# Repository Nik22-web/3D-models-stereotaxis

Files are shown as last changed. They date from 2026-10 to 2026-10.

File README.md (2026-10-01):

# 3D-models-stereotaxis

Рисунок1

# A 3D-Printed Open-Source Stereotaxic Platform for Orthotopic Glioma Cell Implantation into the Mouse Striatum

This repository contains the design files and assembly documentation associated with the manuscript:

**A 3D-Printed Open-Source Stereotaxic Platform for Orthotopic Glioma Cell Implantation into the Mouse Striatum**

**Authors:**  
Kurtova A.I., Esetov N.S., Khamitova Ya.D., Nosov M., Shipunova V.O.

---

## Overview

This repository provides the 3D-printable design files and assembly information required to reproduce and adapt the custom-built stereotaxic platform described in the associated manuscript.

The system consists of:

- one caliper-based needle manipulator;
- two mouse fixation frames;
- 3D-printed structural components;
- commercially available mechanical hardware.

The platform was developed for orthotopic implantation of glioma cells into the mouse striatum and was designed as a low-cost, modular alternative to conventional stereotaxic equipment.

---

## Repository version

The version of this repository corresponding to the manuscript and Supplementary Table S1 is tagged as:

`v1.0-manuscript`

This version should be used when reproducing the configuration described in the manuscript.

---

## Repository contents

The repository contains STL files for the following components developed for the present stereotaxic system:

### Mouse fixation frame support legs

- `first base platform leg.stl`
- `second base platform leg.stl`

### Caliper holder assembly

- `caliper holder.stl`
- `first depth gauge lock.stl`
- `second depth gauge lock.stl`

### Needle retainer

- `needle retainer base.stl`
- `clamping insert.stl`

### Tooth bar assembly

- `bite plate.stl`
- `manual adjustment knob.stl`
- `nose holder.stl`

Additional components of the mouse fixation frame are derived from an upstream open-source stereotaxic/anesthesia platform, as described below.

---

# Assembly Instructions

## 1. Needle retainer assembly

The needle retainer provides rigid fixation of the injection needle while allowing rapid insertion and replacement.

### Components

- needle retainer base;
- clamping insert;
- M3 screw;
- M3 hex nut;
- injection needle.

### Assembly

1. Insert the **M3 hex nut** into the recessed pocket of the clamping insert.
2. Position the **clamping insert** inside the lower slot of the needle retainer base.
3. Mount the assembled needle retainer onto the microscope holder.
4. Insert the **M3 screw** and thread it into the M3 hex nut.
5. Leave sufficient clearance for insertion of the injection needle.
6. Insert the needle and tighten the M3 screw until the needle is securely fixed.

Avoid excessive tightening to prevent damage to the printed components.

---

## 2. Mouse tooth bar assembly

The tooth bar assembly consists of:

- bite plate;
- nose holder;
- manual adjustment knob;
- M6 locking bolt;
- M6 receiving nut;
- retraction spring.

The bite plate contains a central aperture for positioning the upper incisors, while the nose holder prevents upward movement of the anterior part of the head.

### Assembly

1. Insert the **M6 receiving nut** into the recessed pocket of the bite plate.
2. Position the **retraction spring** inside the lower portion of the nose holder.
3. Insert the **nose holder** into the bite plate.
4. Mount the **manual adjustment knob** onto the M6 locking bolt.
5. Insert the locking bolt through the upper opening of the bite plate.
6. Thread the bolt into the M6 receiving nut.
7. Rotate the manual adjustment knob to adjust the position of the nose holder and the clamping force.

---

## 3. Mechanical caliper installation

The mechanical vernier caliper is used to determine vertical needle displacement.

### Installation

1. Attach the **caliper holder** to the upper rail of the microscope stand.
2. Insert the upper jaw of the mechanical caliper into the holder.
3. Verify that the caliper depth gauge moves freely through the corresponding slot in the microscope stand rail.
4. Adjust the caliper position if necessary.
5. Remove the original screw securing the movable microscope stage.
6. Install the **depth gauge retainer** in its place.
7. Insert the caliper depth gauge into the retainer.
8. Secure the depth gauge using the clamping plate.
9. Fasten the assembly using the original microscope-stage screw.
10. After correct alignment has been confirmed, secure the caliper mounting components with adhesive to prevent displacement during stereotaxic procedures.

---

## 4. Needle and catheter installation

Before use:

1. Insert a 29- or 30-gauge needle into polyethylene or PTFE catheter tubing with an inner diameter of approximately 0.3 mm.
2. Place the catheter–needle assembly vertically into the needle retainer.
3. Secure the needle using the locking screw.
4. Connect the opposite end of the catheter tubing to a precision syringe pump.
5. Fill the fluid pathway with PBS and verify that no air bubbles remain before injection.

---

# Fabrication and configuration options

Several components can be produced either by 3D printing or by machining.

## Ear bars

Two alternatives are described:

### Printable version

- fabrication method: mSLA / DLP / SLA;
- material: photopolymer resin;
- STL file: `3DStereotax_earbar.stl`.

### Experimentally used version

- fabricated by machining;
- starting material: steel rod, Ø5 mm × 200 mm.

---

## Support legs

Two printable support-leg designs are provided:

- `first base platform leg.stl`
- `second base platform leg.stl`

These components can be fabricated by FDM using PETG or another suitable FDM polymer.

In the experimentally used configuration, the corresponding support legs were machined from steel.

The starting material for each type of metal support leg was:

**Metal block, 40 × 40 × 100 mm**

---

# Experimental and fully printable configurations

Two configurations should be clearly distinguished.

## Experimentally used configuration

The configuration used in the experiments described in the manuscript consisted of:

- two mouse fixation frames;
- one needle manipulator;
- metal ear bars;
- metal support legs.

As of July 29, 2026, the total material cost of this configuration was:

**USD 63.44**

## Fully printable configuration

A lower-cost configuration can be assembled using the provided and referenced STL files with:

- two mouse fixation frames;
- one needle manipulator;
- photopolymer ear bars;
- FDM-printed support legs.

As of July 29, 2026, the estimated total material cost of this configuration was:

**USD 40.07**

The fully printable configuration is an alternative to the exact configuration used in the reported experiments and should be identified as such when reproduced or described.

---

# Upstream design acknowledgement

Selected components of the mouse fixation frame were adapted from the open-source **Anesthesia Surgery System** developed by the Optogenetics and Neural Engineering (ONE) Core at the University of Colorado School of Medicine.

The upstream project is available at:

https://optogeneticsandneuralengineeringcore.gitlab.io/ONECoreSite/projects/AnestesiaSurgerySystem/

The ONE Core project itself is a remix of earlier open-source rodent stereotaxic designs. The project page identifies a 3D-printed rodent stereotaxic device developed by Lex Kravitz as one upstream source, which itself was based on the Mouse Head Holder designed by John Everett Martin.

For the present stereotaxic system, only selected components of the mouse fixation frame were adapted from this upstream project.

The following elements were developed for the present work:

- needle manipulator;
- tooth bar assembly;
- caliper holder assembly;
- needle retainer;
- support-leg designs;
- overall integration of the stereotaxic system.

The manuscript-associated upstream STL files are:

- `StereotaxONECoreBasev3.stl`
- `StereotaxONECoreSliderv3.stl`
- `3DStereotax_earbar.stl`

The upstream files referenced in Supplementary Table S1 correspond to commit:

`7993f017aa33881c48f564a40fe3eec5df085773`

Third-party and upstream materials remain subject to their original authorship, licensing, and reuse conditions.

The reuse permissions described below for the original materials in this repository do not replace or override the terms applicable to upstream materials.

Users should consult the original upstream project for any additional reuse conditions.

---

## ONE Core acknowledgement

The ONE Core project page requests acknowledgement of the facility in publications using its work.

In the context of the present work, we acknowledge the Optogenetics and Neural Engineering (ONE) Core at the University of Colorado School of Medicine for providing the original open-source design basis for selected components of the mouse fixation frame.

The ONE Core is part of the NeuroTechnology Center at the University of Colorado School of Medicine. According to the original project page, the facility is funded in part by the School of Medicine and by the National Institute of Neurological Disorders and Stroke of the National Institutes of Health under award number P30NS048154.

---

# Use and reuse

The original design materials created by the authors and provided in this repository may be freely:

- downloaded;
- copied;
- used;
- reproduced;
- modified;
- adapted;
- redistributed;
- shared;
- incorporated into other designs;
- used for research;
- used for educational purposes;
- used for commercial or non-commercial purposes.

Users are free to modify the authors' original files and create derivative designs.

The requested condition for reuse is appropriate attribution.

If these files, modified versions of them, or designs substantially derived from them are used in a publication, presentation, thesis, report, repository, or other scholarly output, please cite the associated article.

These reuse terms apply only to original materials for which the authors of this repository have the right to grant such permissions.

Upstream and third-party materials remain subject to their own terms.

---

# Citation

If you use the original design files provided in this repository or substantially derived designs, please cite:

**Kurtova A.I., Esetov N.S., Khamitova Ya.D., Nosov M., Shipunova V.O.  
A 3D-Printed Open-Source Stereotaxic Platform for Orthotopic Glioma Cell Implantation into the Mouse Striatum.  
Journal of Neuroscience Methods.**

Final bibliographic information and DOI will be added after publication.

---

# Modifications and derivative designs

Users are encouraged to modify and improve the system according to their experimental requirements.

Modified versions should be clearly identified as derivative designs.

Changes in:

- geometry;
- dimensions;
- materials;
- manufacturing method;
- component arrangement;
- assembly procedure

may affect the mechanical or experimental performance of the system.

Modified versions should therefore not be described as experimentally validated by the original authors unless they correspond to the configuration evaluated in the associated publication.

---

# Disclaimer

The design files and documentation are provided without warranty of any kind.

Users are responsible for:

- verifying the mechanical integrity of reproduced or modified components;
- determining whether the system is suitable for their intended application;
- complying with applicable institutional and ethical requirements;
- complying with animal-use regulations;
- following appropriate laboratory and surgical safety procedures.

---

# Contact

For questions regarding the design or associated manuscript:

**Anastasia I. Kurtova**  
Corresponding author

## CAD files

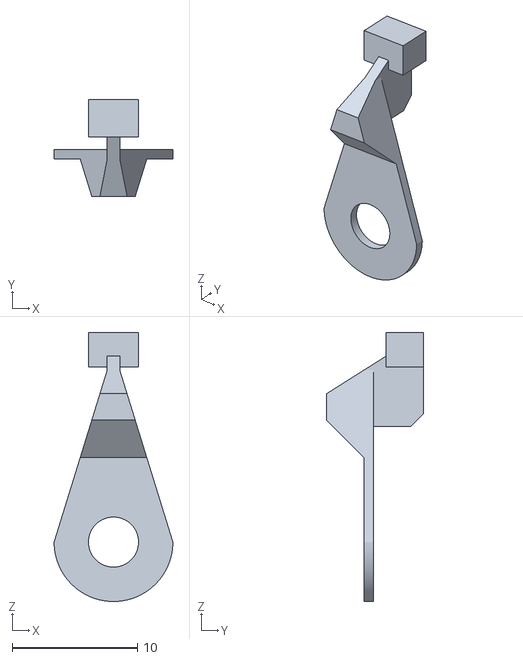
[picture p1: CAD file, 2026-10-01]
caliper holder/second depth gauge lock.stl
9.50 x 7.75 x 21.5

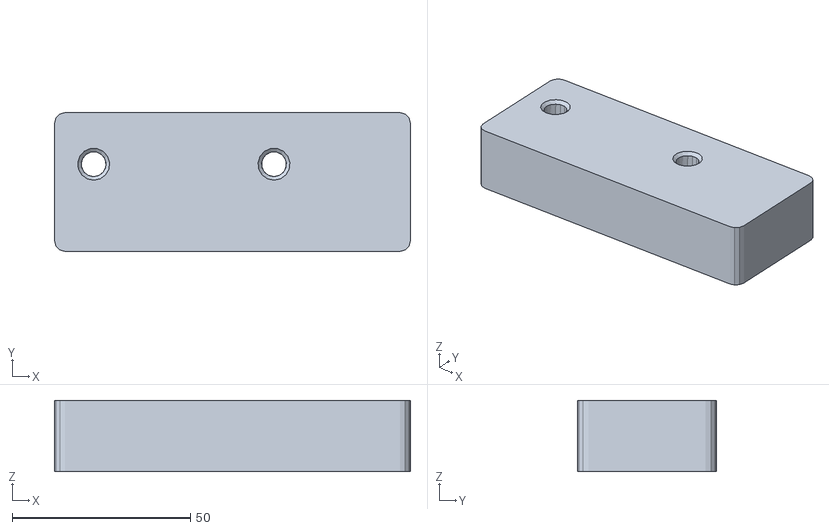
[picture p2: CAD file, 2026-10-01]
mouse fixation frame legs/first base platform leg.stl
100.0 x 39.0 x 20.0

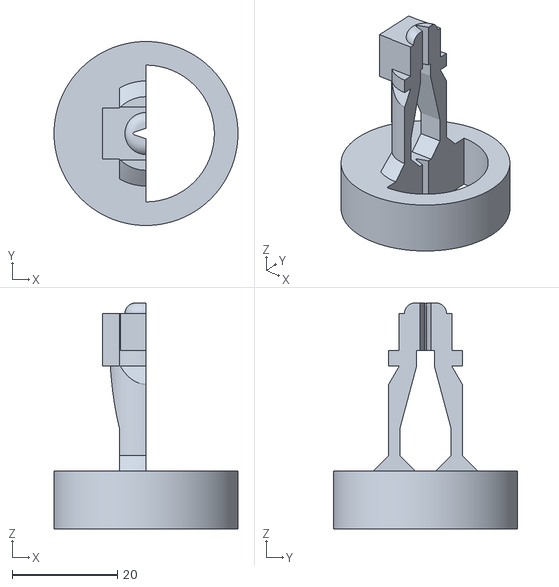
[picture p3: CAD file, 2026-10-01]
needle retainer/needle retainer base.stl
35.0 x 35.0 x 43.0

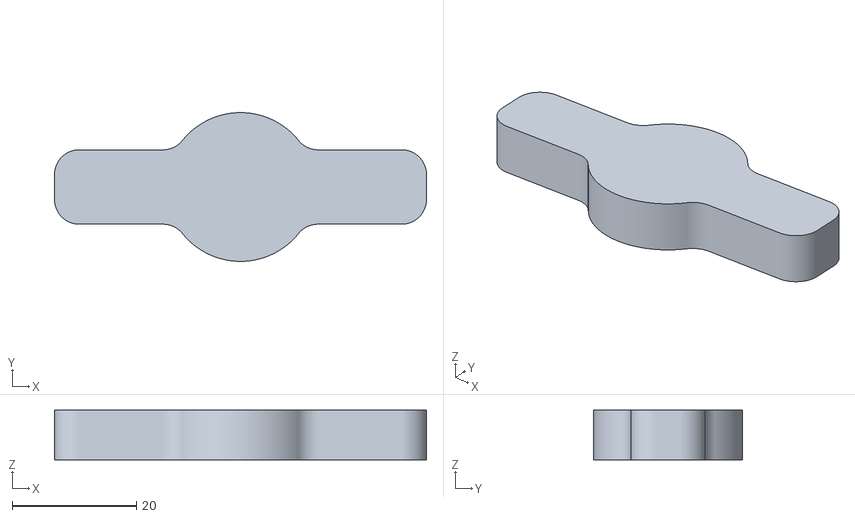
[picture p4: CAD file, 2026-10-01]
tooth bar/manual adjustment knob.stl
60.0 x 24.0 x 8.00

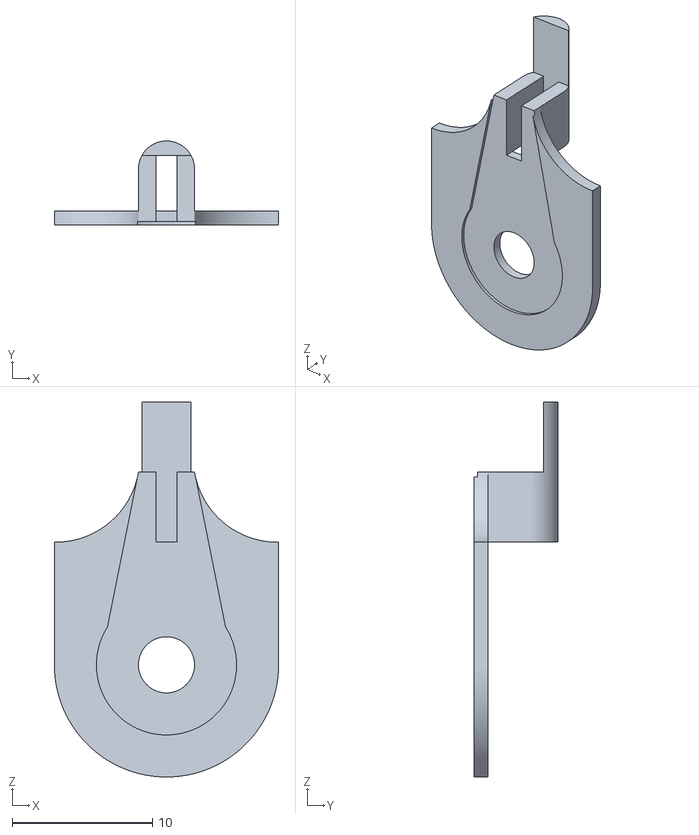
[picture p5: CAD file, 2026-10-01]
caliper holder/first depth gauge lock.stl
16.0 x 6.00 x 26.7

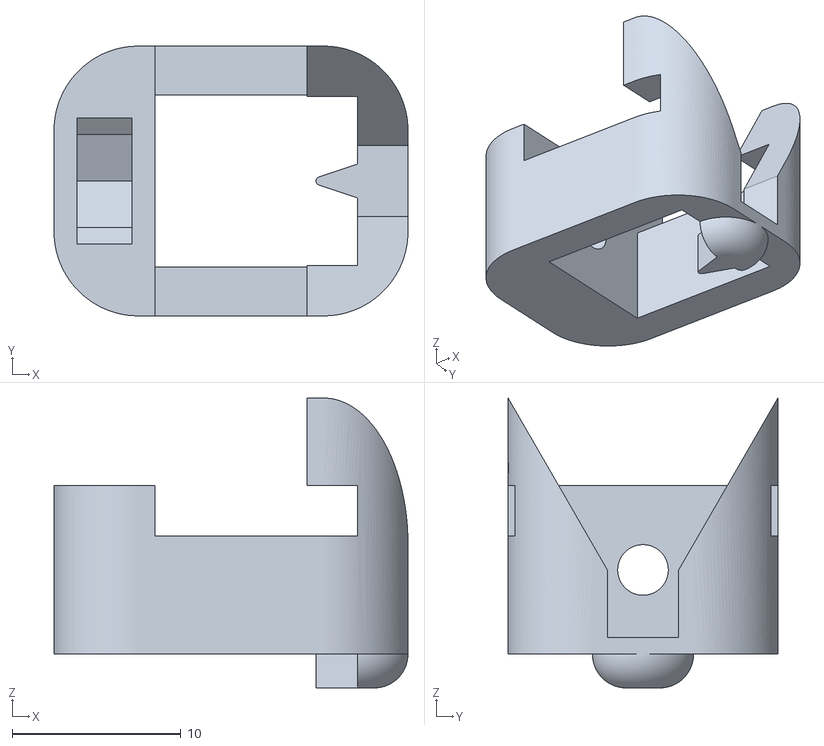
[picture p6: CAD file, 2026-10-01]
needle retainer/clamping insert.stl
21.0 x 16.0 x 17.2

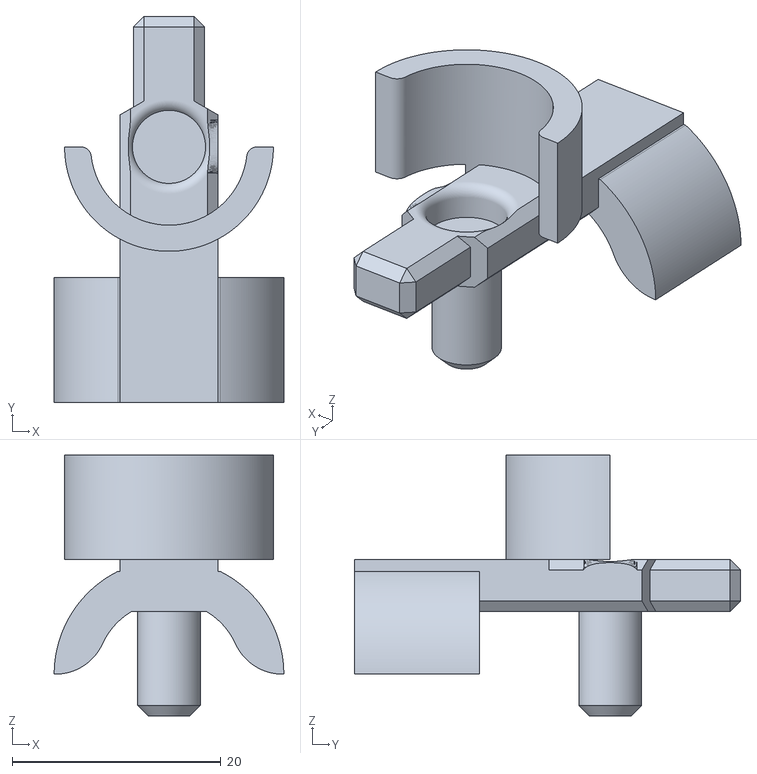
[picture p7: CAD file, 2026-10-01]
tooth bar/nose holder.stl
22.0 x 37.0 x 25.0

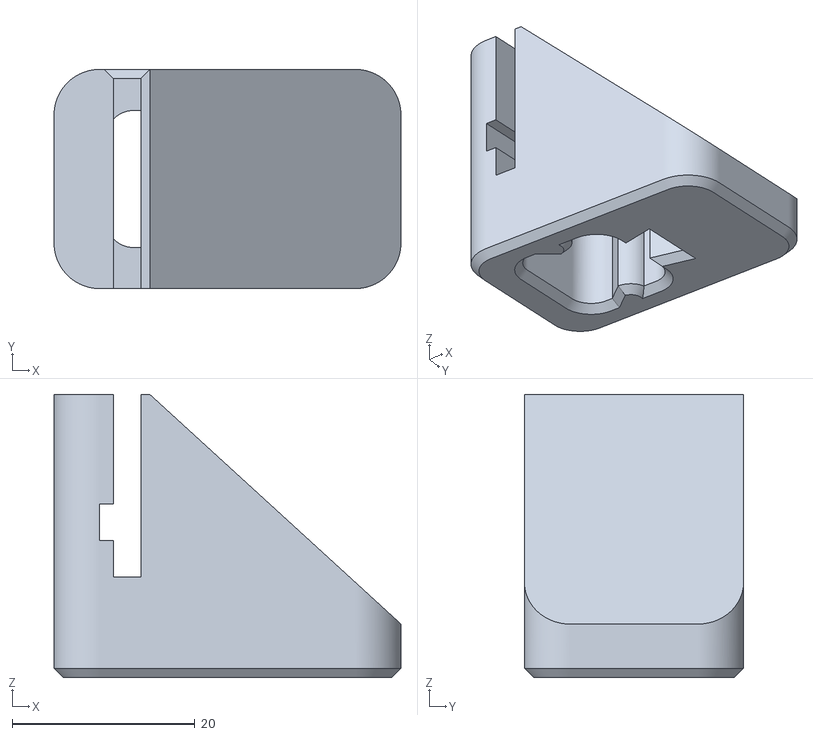
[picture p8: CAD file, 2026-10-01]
caliper holder/caliper holder.stl
38.0 x 24.0 x 31.0

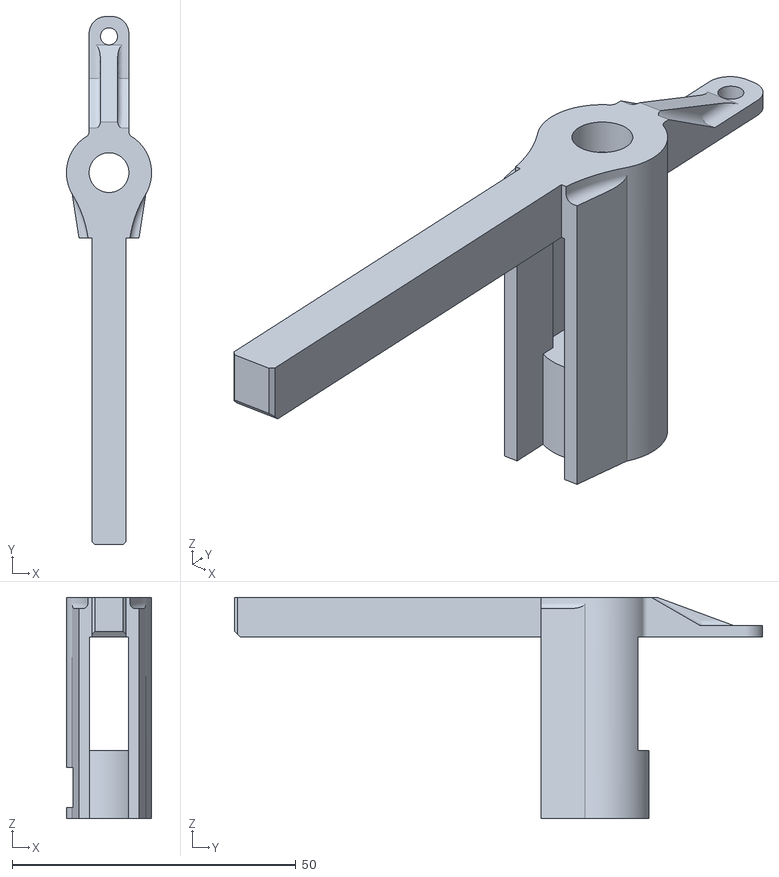
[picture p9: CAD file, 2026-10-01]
tooth bar/bite plate.stl
15.0 x 93.0 x 39.0

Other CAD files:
mouse fixation frame legs/second base platform leg.stl
